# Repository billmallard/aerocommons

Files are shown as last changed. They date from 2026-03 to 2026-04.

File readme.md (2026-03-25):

# AeroCommons — MAOS Platform

### 🌐 [aerocommons.org](https://aerocommons.org) — Project website with full documentation, articles, and design updates

**Mobile Aviation Operating System**
*An open-source experimental aircraft development project*

---

> **This is a design and development project, not a flying aircraft.**
> The MAOS does not yet exist as a physical airplane. What exists right now is a growing body of engineering design work, analysis, and documentation — all of it published here as it is produced. If you found this page, you are watching the project from the beginning.

---

## What Is This?

AeroCommons is building an experimental aircraft called the **MAOS — Mobile Aviation Operating System**.

The concept: a four-seat, IFR-equipped, series-hybrid experimental aircraft that a single builder can construct in a two-car garage, transport on a road-legal trailer, and deploy from a remote airstrip without hangar support. It targets a 20,000 ft ceiling, carries TKS ice protection, and uses a novel propulsion architecture — two motorcycle-derived generator engines driving contra-rotating electric motors — that provides meaningful redundancy at every stage of the power chain.

It is designed and built under **FAA Experimental Amateur-Built (E-AB)** rules, the same regulatory framework used by thousands of homebuilt aircraft flying today. This means the builder constructs more than 51% of the aircraft themselves, and the FAA issues a special airworthiness certificate on that basis.

The MAOS does not exist yet as metal and composite. The design work is underway. This repository is where that work lives.

---

## What Is GitHub? (A Note for Pilots)

If you arrived here from the EAA forums, a fly-in conversation, or a link someone sent you, and you have never used GitHub before — welcome. Here is what you need to know.

**GitHub is a platform for storing, versioning, and collaborating on files.** It was built by software developers, so the interface can feel foreign if your world is airplanes rather than code. But the underlying idea is simple and useful for a project like this:

- Every document, drawing, and design file we produce is stored here
- Every change to every file is recorded, with a timestamp and a description of what changed and why
- Anyone in the world can read the files, download them, and propose changes
- Discussions happen in the open, attached to specific documents or topics

Think of it as a combination of a **shared filing cabinet**, a **change log**, and a **community forum** — one where the entire history of every decision is preserved and searchable.

You do not need to understand software development to participate here. You need to be willing to read, ask questions, and share your experience.

---

## Where We Are Right Now

The following formal design documents have been completed and are in the repository:

| Document | Title | Status |
|---|---|---|
| DWG MAOS-GA-001 | General Arrangement — Artist's Concept | Complete |
| DWG MAOS-PM-002 | Project Briefing — Team & Propulsion Architecture | Complete |
| MAOS-TRL-DEV-001 Rev A | Trailer & Ground Support Development Plan | Complete |
| MAOS-ECS-DEV-001 Rev B | Environmental Control System Development Plan | Complete |

**Open design decisions** currently under active analysis include: final wingspan (which drives trailer length and wing loading), flap vs. flapless configuration, HV bus voltage, propulsion motor final selection, and pressurization system design.

The design is not frozen. This is the point in the project where decisions are still being made and where experienced input has the most value.

---

## The Aircraft — Key Concepts

**Airframe:** Pod-and-boom configuration. A cylindrical pressure pod carries the crew and systems. A tail boom carries the empennage and propulsion motors. High wing with V-struts. Fixed faired tricycle gear.

**Propulsion:** Series hybrid. Two Honda 400cc motorcycle-derived engines mounted in the wing run as pure electrical generators. Their output feeds a common high-voltage bus alongside a flight battery pack. Contra-rotating electric motors on the tail boom provide thrust. No single failure produces a total power loss.

**Wing:** Single-piece removable high wing. Generators are integrated into the wing structure. Wing removal and installation uses the trailer's built-in crane system — no hangar, no forklift, no external ground equipment.

**Trailer:** A purpose-built ground support system based on an enclosed aluminum gooseneck car hauler. An overhead crane beam runs the length of the trailer interior. The aircraft is transported, deployed, and recovered entirely from the trailer. Road legal within Texas highway envelope.

**ECS:** Full climate control from first flight (v1.0), with all structural provisions for pressurization built in so that pressurization (v1.1) is an installation upgrade rather than a redesign.

**Avionics:** IFR equipped. EFIS-based glass panel. All-weather capable including TKS fluid ice protection.

**Regulatory:** FAA Experimental Amateur-Built, 51% rule. The aircraft will carry an experimental airworthiness certificate.

---

## How This Project Is Being Designed

The MAOS uses a structured **AI-assisted design methodology** that we believe is genuinely novel for homebuilt aircraft development.

Rather than using AI as a search tool or writing assistant, the project runs a **multi-agent design board** — a set of specialized AI agents assigned to Aerodynamics, Structures, Propulsion, Systems, Manufacturing, and Safety, coordinated by a Chairman agent. These agents hold formal board sessions, surface conflicts between disciplines, and produce structured decision records.

Every open design question is tracked as an explicit **decision gate**. No decision is resolved informally. Every gate has a current recommendation, a rationale, and remains open for revision until it is formally closed.

All session transcripts, agent SKILL files, board agendas, decision records, and analysis outputs are published in this repository as they are produced. The methodology itself is open — any builder can fork it and apply it to their own project.

This is not a replacement for engineering judgment. The agents surface conflicts and structure analysis. The human makes decisions.

---

## Manufacturing Philosophy

The MAOS is designed to be built by **one person with basic tools**. Not a well-equipped professional shop. A two-car garage with hand tools, a drill press, and internet access.

Primary structure uses:
- **Aluminum sheet and extrusions** — cut to DXF files by SendCutSend, OSH Cut, or equivalent. Parts arrive flat and ready to assemble.
- **Foam-core fiberglass composite** — hot-wire cut foam cores, hand-laid fiberglass. No autoclave. No CNC.
- **3D printed tooling and formers** — FDM for jigs, fixtures, and non-structural components. Never primary structure.
- **COTS hardware** — McMaster-Carr, Aircraft Spruce, standard commercial sources for everything else.

All design files are published in open formats: STEP, STL, DXF. Primary CAD tools are FreeCAD and OpenVSP. No vendor lock-in.

---

## How to Follow This Project

**You do not need an account to read everything in this repository.** All documents, drawings, and files are publicly visible.

If you want to do more than read:

### ⭐ Star the repository
The star button is in the top-right corner of this page. Starring a repository on GitHub is the equivalent of bookmarking it and telling the platform you find it interesting. It helps the project be discovered by others, and it tells us the work is reaching people.

### 👁️ Watch the repository
The **Watch** button (also top-right) lets you subscribe to activity. You can choose to be notified when new documents are published, when discussions open, or when decisions are recorded. You can tune the notification level to whatever suits you — from everything to only major releases.

### 💬 Join the Discussions
The **Discussions** tab at the top of this page is where the community conversation happens. You can:
- Ask questions about the design
- Share experience from your own builds or flying that's relevant to a design decision
- Follow threads on specific topics (propulsion, trailer ops, avionics, etc.)
- Propose an idea or flag a concern

Discussions are indexed and searchable. A question you ask today may help a builder three years from now.

### 🐛 Open an Issue
If you spot a problem in a document — a calculation that doesn't look right, a specification that conflicts with another, or a decision that seems to be missing — open an **Issue**. The Issues tab is designed for exactly this. It creates a tracked record of the concern and ensures it gets addressed.

### 🍴 Fork the Repository
If you want your own copy of the design files to experiment with, propose major changes, or adapt for your own project, you can **Fork** the repository. This creates a complete copy under your own GitHub account. Any changes you make to your fork are yours — and if you want to propose those changes be incorporated into the main project, you submit a **Pull Request**.

---

## Who We Are Looking For

The MAOS is a serious engineering project aimed at building a real aircraft. The people who will make it successful are:

- **Experienced homebuilders** who have completed or are building EAA projects and can ground-check design assumptions against shop reality
- **Pilots** — particularly those with IFR, mountain, or backcountry experience who can speak to the operational requirements the design is meant to serve
- **Aerospace and mechanical engineers** who want to apply professional judgment to a project that actually matters to them
- **Makers and fabricators** with composite, aluminum, or electrical skills
- **Software and firmware developers** interested in the open-source FADEC and control systems

You do not have to be credentialed to contribute. You have to be serious, specific, and willing to be wrong.

---

## Principles

1. **Safety through design, not pilot skill.** The aircraft must be inherently stable and departure-resistant. A bad moment should not become a fatal one.
2. **If a determined amateur cannot build it, the design has failed.** Complexity is a bug, not a feature.
3. **Weight is always the enemy.** Every component justifies its existence in grams, not just function.
4. **Open from the first session.** Nothing is held back for a later announcement. The work is public as it happens.
5. **The 51% rule is the design rule.** The builder-fabricated portions are the capable, interesting, achievable portions — not a compliance exercise.

---

## Links

- **Website:** [aerocommons.org](https://aerocommons.org)
- **Contact:** [contact@aerocommons.org](mailto:contact@aerocommons.org)
- **Discussions:** [github.com/billmallard/aerocommons/discussions](https://github.com/billmallard/aerocommons/discussions)

---

*AeroCommons is an open-source experimental aircraft development project. The MAOS has not yet flown. All specifications are design targets subject to revision. Nothing in this repository constitutes airworthiness approval or certification of any kind. Build and fly at your own judgment and risk.*

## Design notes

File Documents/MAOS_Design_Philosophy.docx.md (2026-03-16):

**MOBILE AVIATION OPERATING SYSTEM**

*Project Design Philosophy & North Star Statement*

Version 0.1  //  March 2026  //  DRAFT

# **North Star Statement**

*This aircraft is designed as a complete mobile aviation operating system. The airplane and trailer are co-equal components, designed together from first principles. The system requires no fixed infrastructure — no hangar, no FBO, no ground crew. A single pilot can deploy, operate, and recover the system from any suitable airstrip.*

*Every design decision is evaluated against this principle. Complexity that serves the operating system is acceptable. Complexity that serves only aesthetics or marginal performance gains is rejected. The airplane must be buildable, maintainable, and operable by one person with the tools that travel with it.*

This is the filter through which every design decision passes. When tempted to add a feature, add weight, or add complexity, return here first.

# **What This Is — And Is Not**

This is not a trailerable airplane. Trailerable airplanes tolerate being trailered. This system is designed around the trailer as a first-class component from day one.

The distinction matters because it changes every priority:

* A trailerable airplane compromises to fit on a trailer. This airplane is designed with the trailer as its ground station.

* A trailerable airplane stores in a hangar and occasionally gets trailered. This system has no hangar — the trailer is the hangar.

* A trailerable airplane requires two people and a forklift to rig. This system deploys solo, in under an hour, from a pickup truck.

The closest analogy is a boat on a trailer. The owner arrives at any suitable body of water, launches, operates, recovers, and drives away. No marina slip required. No dock fees. No dependence on fixed infrastructure. This is that — for aviation.

# **What This System Enables**

The operating system concept transforms the owner's cost structure and operational freedom completely:

* No hangar lease — potentially the single largest recurring cost in personal aviation, eliminated.

* No dependence on FBO services for routine operations.

* Maintenance at home, in the trailer, with the integrated workbench and tool storage.

* The airplane can be stored at home, in a driveway, legally — like a boat.

* Fly from any suitable strip in a region, not just home base. Tow to a new area and operate from there.

* True cross-country independence: depart from a grass strip, land at a paved field, drive the trailer to meet yourself if needed.

The lifestyle this enables is different in kind, not just degree. This is not flying from Airport A to Airport B and back. This is towing your operating system to a region, flying from multiple local strips, and moving on when ready.

# **Design Philosophy**

## **Rutan's Rule**

Safety through inherent stability. The configuration must resist departure without demanding pilot heroics. A bad moment must not become a fatal moment.

## **Bede's Rule**

If a determined amateur with modest tools cannot build this, the design has failed before it flew. Complexity is a bug, not a feature. A sophisticated airplane can and should be buildable by one person in a two-car garage on a reasonable budget.

## **The Operating System Rule**

Every component — airframe, powerplant, systems, trailer, crane — is evaluated as part of a single integrated system. A component that is excellent in isolation but degrades the operating system is the wrong component.

When a design decision is genuinely uncertain, ask: which choice better serves the solo operator at a remote strip with the tools in the trailer?

# **Design Priorities**

In strict order. A lower priority never overrides a higher one.

1. Stall/departure resistance — canard or inherently safe configuration preferred.

2. Structural simplicity — minimum part count, minimum joints, minimum skill at each build step.

3. Repairability in the field with basic tools and materials from Aircraft Spruce or equivalent.

4. Performance — efficiency and speed matter, but not at the cost of priorities 1–3.

5. Aesthetics — a good design looks right, but ugly flies fine.

# **The Decision Filter**

Before accepting any design feature, ask these questions in order:

* Does this serve the operating system, or only the airplane?

* Can a competent amateur build or repair this with tools that travel in the trailer?

* What does this weigh, and does it justify that weight?

* If this fails at a remote strip, what is the recovery path?

* Does "that's how production aircraft do it" justify this — or is that a lazy answer?

If a feature cannot survive this filter, it does not belong in the design. Note the idea in the design log and move on.

# **Non-Negotiable Constraints**

These are not preferences. They are constraints that define what this project is.

* Never propose a feature that requires a professional machine shop to fabricate.

* Never accept retractable gear on the primary design — the complexity and failure modes are incompatible with the operating system concept.

* Never optimize for aesthetics at the expense of buildability.

* Never ignore weight — always ask what the lightest acceptable solution is before proposing a heavier one.

* Never design around a single-source supplier with no track record in the homebuilder community.

# **Current Configuration Snapshot**

This is the working design as of initial concept phase. All figures are targets subject to revision.

## **Airframe**

**Configuration:**  High-wing, pod-and-boom, tricycle gear, fixed faired main gear

**Seats:**  4 (wide cabin — 46" minimum, Cherokee Six reference)

**Wing:**  One-piece, removable, tubular aluminum spar (BD-4 inspired), laser-cut ribs

**Wing area:**  \~140 ft²  |  Span: \~37.4 ft  |  AR: 10  |  Loading: \~17.5 lbs/ft²

**Airfoil:**  Riblett GA35-615 (15% root / 12% tip) — working assumption

**Primary structure:**  Aluminum semi-monocoque; flat-cut parts from SendCutSend

**IFR / Ice:**  IFR capable; TKS ice protection preferred

## **Powerplant (Primary Path)**

**Engine:**  Viking 195T (Honda-based, 195 HP, turbocharged, FADEC, mogas)

**Alternates:**  ULPower UL520T; Kawasaki Inline 4 Turbo (provision only, pending certification)

**Cooling:**  Liquid-cooled; heat exchanger provides cabin heat

## **Performance Targets**

**Cruise:**  155 KTAS

**Range:**  1,000 nm  |  Endurance: 7 hrs (5 hrs flying \+ reserves)

**Useful load:**  1,200 lbs including fuel

**Gross weight:**  \~2,430 lbs

**Empty weight target:**  \~1,230 lbs

**Service ceiling:**  17,500–20,000 ft

## **Trailer System**

**Concept:**  Integrated ground station — horizontal boom crane deploys from trailer roof

**Crane:**  Horizontal boom, min. half-wingspan reach; rotating cradle engages wing at strut fittings

**Sequence:**  Disconnect 4 pins \+ QD fittings, lift 6", rotate 90°, retract — wing stowed

**Target time:**  \~65 min solo (45 min with practice)

**Trailer features:**  Shore power, inverter, workbench, tool storage, wing stowed above fuselage

**Regulatory:**  FAA Experimental Amateur-Built (51% rule)

*This document is the project north star. Return to it before accepting any design change that adds weight, complexity, or dependency on fixed infrastructure. If a decision is consistent with this document, it is probably right. If it conflicts, it requires extraordinary justification.*

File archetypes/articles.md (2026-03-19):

---
title: "{{ replace .Name "-" " " | title }}"
date: {{ .Date }}
description: ""
tags: []
author: "AeroCommons Design Board"
session: ""
summary: ""
draft: false
---

<!-- 
  AEROCOMMONS ARTICLE TEMPLATE
  ─────────────────────────────
  title:       Full title of the post
  date:        ISO 8601 — YYYY-MM-DDTHH:MM:SS-06:00
  description: One sentence shown in article cards and meta tags
  tags:        Array of lowercase tags e.g. ["board-meeting", "propulsion", "structures"]
  author:      Who or what produced this (e.g. "AeroCommons Design Board")
  session:     Optional — board session ID if applicable (e.g. "BOARD-004")
  summary:     Optional — override for the article card excerpt
  draft:       Set to true to publish to repo without displaying on site
-->

Body content begins here. Markdown is fully supported.

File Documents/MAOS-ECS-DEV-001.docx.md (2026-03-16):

  
**MAOS AIRCRAFT PROJECT**

**Environmental Control System**

Development Plan

Pressurization · Climate Control · Controller Electronics

Document: MAOS-ECS-DEV-001  
Revision: A (Draft)  
Date: March 12, 2026

# **1\. System Overview & Design Philosophy**

The MAOS Environmental Control System (ECS) provides cabin pressurization, heating, cooling, ventilation, and dehumidification as a single integrated subsystem. Unlike conventional light aircraft that bleed compressed air from engine turbochargers, the MAOS ECS is fully electric: all compressors, fans, valves, and controllers run from the aircraft DC electrical bus with no pneumatic connections to the wing-mounted generators.

This architecture is driven by the pod-and-boom configuration. The wing-to-pod interface is the primary modularity boundary for transport and assembly. Keeping the ECS entirely within the pod means that wing attachment and removal requires only structural fasteners, electrical connectors, and fuel quick-disconnects. No hot pneumatic ducting crosses this boundary.

## **1.1 Design Requirements**

| Parameter | Requirement |
| :---- | :---- |
| Cabin volume | \~150–180 cu ft (4 occupants \+ baggage) |
| Max flight altitude | 25,000 ft (Kawasaki engine max operating) |
| Target cabin altitude | 8,000 ft maximum at all flight altitudes |
| Max differential pressure | 5.5 psi (at 25,000 ft / 8,000 ft cabin) |
| Normal differential | 3.5 psi (at 20,000 ft / 8,000 ft cabin) |
| Ventilation flow | 10 CFM/person minimum, 40–60 CFM total |
| Ground cooling | Full AC at 40°C ambient, 4 occupants, sun load |
| Ground heating | Cabin to 20°C from \-10°C ambient within 10 min |
| Max ECS power draw | 5 kW peak (ground hot day), 2–3 kW cruise |
| Target weight (complete) | 18–25 kg (40–55 lbs) all-in |
| Pod-external connections | Electrical only. Zero pneumatic connections. |

## **1.2 System Architecture Summary**

The ECS consists of two independent compression loops plus shared distribution and controls:

* **Pressurization loop:** Electric air compressor draws ambient air through filtered pod inlet, compresses to cabin pressure, delivers to mixing plenum. Outflow valve on aft bulkhead regulates cabin pressure.

* **Climate loop:** Closed-circuit vapor-cycle refrigerant system (R-1234yf) with reversible heat pump capability. EV-class scroll compressor, condenser with ram air and electric fan, evaporator in cabin air path, electronic expansion valve.

* **Controls:** Custom ESP32-based controller managing both loops, cabin pressure regulation, temperature control, safety interlocks, and CAN bus integration with aircraft systems.

# **2\. Development Phases**

Development proceeds in five phases. The key principle is that each phase produces a testable system that validates assumptions before committing to the next level of integration. The pod-only architecture makes this possible: every phase through Phase 3 can be tested on the ground with the pod on its trailer.

| Phase | Objective | Deliverable | Duration | Cost Est. |
| :---- | :---- | :---- | :---- | :---- |
| 1 | Requirements & component selection | BOM, schematic, sourced parts | 6–8 weeks | $2,000–$3,500 |
| 2 | Bench test rig | Working ECS on open frame | 8–12 weeks | $3,000–$5,000 |
| 3 | Pod integration | ECS installed in pressure shell | 8–12 weeks | $2,000–$4,000 |
| 4 | Ground pressure test | Sealed pod holds 5.5 psi diff. | 4–6 weeks | $500–$1,500 |
| 5 | Flight test integration | ECS operational in flight | Ongoing | Incl. in flight test |

## **2.1 Phase 1: Requirements Lockdown & Component Selection**

**Duration:** 6–8 weeks

**Objective:** Finalize thermal loads, select all major components, produce complete bill of materials, and design the controller electronics for PCB outsourcing.

### **2.1.1 Thermal Load Analysis**

Before selecting hardware, quantify the actual thermal loads for the three design cases:

1. **Ground hot day (design driver):** 40°C ambient, direct solar through windscreen (\~800 W/m² on \~0.5 m² glazing \= 400W solar gain), 4 occupants at 100W metabolic each, avionics heat \~100W. Total cooling load approximately 900–1,100W. Add safety margin: size climate compressor for 3–4 kW cooling capacity.

2. **Cruise at 20,000 ft:** OAT approximately \-25°C, pressurization compressor adds \~40°C to inlet air, cabin heat loss through fuselage skin significant. Net heating load likely 500–800W. Heat pump mode or pressurization compression heat may suffice.

3. **Cold soak / ground cold:** \-10°C ambient, need to warm cabin to 20°C. Heat pump COP drops at low ambient temps. May need supplemental resistive heat element (\~1 kW PTC heater as backup) for initial warmup.

### **2.1.2 Component Selection**

All major components should be selected during this phase. The following table identifies the target components and selection criteria:

| Component | Target Specification | Sourcing Notes |
| :---- | :---- | :---- |
| Pressurization compressor | Electric centrifugal or scroll, 60 CFM at 2:1 PR, 12–48V or 200–400V DC, \<4 kg | EV/fuel cell air supply units (e.g., Busch, Rotrex, Thomas). Evaluate automotive fuel cell cathode air compressors. |
| Climate compressor | EV scroll compressor, R-1234yf, 3–4 kW cooling, 200–400V DC, \<7 kg | Denso, MAHLE, Hanon Systems, Valeo. Used EV parts from Tesla Model 3/Y, Hyundai Ioniq salvage as test units. |
| Condenser | Microchannel, \~2–3 kW rejection, ram air \+ 12V fan, \<3 kg | Automotive universal condensers. Size for ground ops with fan only (no ram air). |
| Evaporator | Compact plate-fin, fits under-floor or behind panel, \<2 kg | Universal automotive evaporator cores. Custom bracket via 3D print / sheet aluminum. |
| Outflow valve | Motorized butterfly or poppet, 2–3 in diameter, proportional control | COTS motorized damper or custom: stepper motor \+ 3D-printed or waterjet butterfly. Fail-open design mandatory. |
| Expansion valve | Electronic expansion valve (EEV), R-1234yf rated | Danfoss, Sanhua, or automotive OEM. EEV preferred over TXV for heat pump reversibility. |
| Reversing valve | 4-way valve for heat pump mode | Standard HVAC 4-way reversing valve, R-1234yf compatible. |
| Cabin pressure sensor | Absolute pressure, 0.1% accuracy, 6–15 psia range | Honeywell ABP2 series or TE MS5611. Dual redundant. |
| Temperature sensors | NTC thermistors or digital (DS18B20), cabin \+ evap \+ condenser \+ ambient | Commodity parts. 6–8 sensors total across system. |
| Dump valve | Manual cable-actuated, 3–4 in, fail-open | Aircraft Spruce or custom. Pilot-accessible red handle, zero electrical dependency. |
| PTC heater (backup) | 1–2 kW, 12V or HV DC, self-regulating | Automotive PTC cabin heater elements. Compact, intrinsically safe. |

### **2.1.3 Controller Electronics Design**

The ECS controller is the heart of the system and the primary custom-development effort. It manages cabin pressure regulation, climate control, safety interlocks, and system health monitoring. The architecture uses an ESP32-S3 as the main processor with purpose-built I/O and power driver boards.

**Controller architecture:** One main controller board (ESP32-S3) handles all ECS logic. A separate power driver board carries the high-current switching for compressor enable, fan PWM, valve actuation, and PTC heater switching. The two boards connect via a ribbon cable. This separation keeps noise-sensitive analog sensing away from high-current switching.

Phase 1 deliverables for electronics:

1. Complete schematic capture in KiCad (open-source, PCB fab houses accept natively)

2. Bill of materials with LCSC/DigiKey/Mouser part numbers for all components

3. PCB layout to 90% completion, ready for review before sending to fab

4. Firmware architecture document defining state machines, control loops, and CAN message definitions

5. Gerber files and pick-and-place files ready for JLCPCB or PCBWay assembly

### **2.1.4 Main Controller Board — Block Diagram**

The main board includes:

* **ESP32-S3-WROOM-1 module:** Dual-core 240 MHz, WiFi/BLE for ground diagnostics and firmware updates, sufficient ADC channels and GPIO.

* **Pressure sensing:** Dual redundant absolute pressure sensors (SPI or I2C), 0.1% accuracy. Cross-checked in firmware; disagreement triggers alert.

* **Temperature inputs:** 8-channel analog mux for NTC thermistors (cabin air, evaporator surface, condenser air, ambient inlet, compressor discharge, refrigerant suction, refrigerant discharge, electronics enclosure).

* **Humidity sensor:** SHT40 or BME280 for cabin humidity monitoring and dehumidification control.

* **CAN transceiver:** SN65HVD230 or MCP2562 for integration with aircraft CAN bus. Receives altitude, airspeed, and electrical bus status. Transmits ECS status and alerts.

* **Display interface:** SPI output to a small TFT or OLED for maintenance/debug. In flight, ECS status displays on the primary EFIS via CAN.

* **SD card slot:** Flight data logging of all ECS parameters at 1 Hz for post-flight analysis.

### **2.1.5 Power Driver Board — Block Diagram**

The power driver board includes:

* **Pressurization compressor driver:** If using a brushless DC compressor, either an integrated inverter (preferred) or an external ESC. Enable/speed command from main controller via PWM or analog voltage.

* **Climate compressor driver:** EV scroll compressors typically include an integrated inverter accepting a CAN or PWM speed command. The power board provides the HV DC contactor and precharge circuit.

* **Fan PWM outputs:** 2 channels (condenser fan, cabin recirculation fan), MOSFET-driven, 12V, 5A each.

* **Outflow valve driver:** Stepper motor driver (TMC2209 or A4988) for proportional valve control. Endstop inputs for full-open and full-closed positions.

* **EEV driver:** Stepper driver for electronic expansion valve (500-step typical).

* **Reversing valve:** Relay or MOSFET for 4-way valve solenoid actuation.

* **PTC heater switching:** High-side MOSFET switch with current sensing for the backup heater element.

* **Power monitoring:** INA226 or equivalent for bus voltage and current measurement on both LV (12/28V) and HV (if applicable) buses.

## **2.2 Phase 2: Bench Test Rig**

**Duration:** 8–12 weeks

**Objective:** Prove the thermodynamics, validate component selections, tune the control loops, and identify integration issues before touching the actual pod.

The bench rig is the most important phase. It catches problems when they are cheap to fix. Build it on a workbench or rolling cart using a simplified test enclosure.

### **2.2.1 Test Enclosure**

Build a sealed plywood or insulated foam box roughly approximating the pod internal volume (about 4 ft × 4 ft × 8 ft). It does not need to hold 5.5 psi differential. Use a shop vacuum or auxiliary blower connected to the outflow path to simulate cabin leakage and draw air through the system. The goal is airflow and thermal testing, not pressure testing.

For the pressurization compressor specifically, test it against a throttled outlet to confirm it can achieve the required pressure ratio and flow rate at the expected inlet pressures. You cannot simulate 20,000 ft ambient pressure on a bench, but you can verify the compressor performance curve and extrapolate.

### **2.2.2 Bench Test Sequence**

1. **Climate loop only (no pressurization):** Charge refrigerant circuit, run cooling mode, verify evaporator temperature, condenser rejection, and cabin temperature pulldown in the test box. Tune EEV superheat control.

2. **Heat pump mode:** Reverse the 4-way valve, verify heating capacity and COP at various ambient conditions. Test defrost logic if evaporator ices.

3. **Pressurization compressor:** Run independently. Measure flow vs. pressure ratio curve. Verify discharge temperature. Test speed control response.

4. **Combined operation:** Run both loops simultaneously. Verify no interactions (electrical noise, vibration coupling). Test worst-case power draw.

5. **Controller integration:** Install the prototype PCBs. Run automated test sequences. Verify all sensor readings, actuator responses, safety interlocks. Test CAN bus communication with a simulated aircraft bus.

6. **Failure mode testing:** Simulate sensor failures (disconnect each sensor individually), compressor failures (kill power to each compressor), and electrical bus faults. Verify the controller responds correctly to each scenario.

### **2.2.3 Instrumentation**

The bench rig should be heavily instrumented beyond what the flight controller needs. Add a USB data acquisition system logging at 10 Hz minimum, with thermocouples at every point in the refrigerant circuit, pitot tubes in the air ducts for flow measurement, a watt meter on the electrical supply, and a refrigerant pressure gauge set. This data validates the thermal model and catches issues the flight sensors might miss.

## **2.3 Phase 3: Pod Integration**

**Duration:** 8–12 weeks

**Objective:** Install the proven bench system into the actual pod structure, route ducting, mount the condenser, seal penetrations, and verify fitment.

By this point, the thermodynamics are validated and the controller is tuned. This phase is about packaging, routing, and sealing. The pod is on the trailer with no wing attached. Shore power (120/240V AC via an inverter or directly) drives the system.

Key integration tasks:

1. **Condenser mounting:** Install on lower aft pod surface with NACA scoop or flush inlet for ram air. Verify fan-only ground cooling capacity before assuming any ram air credit.

2. **Evaporator installation:** Mount in under-floor plenum or behind aft cabin panel. Route cabin air recirculation ducting. Verify condensate drain path exits the pressure shell through a trapped drain (P-trap or check valve to prevent pressure loss).

3. **Pressurization inlet:** Install filtered inlet on pod exterior with rain/FOD protection. Route to pressurization compressor. Consider inlet location relative to exhaust and engine fumes.

4. **Outflow valve:** Install on aft pressure bulkhead. Verify full-open and full-closed positions. Test manual dump valve independently.

5. **Controller and wiring:** Mount controller enclosure in avionics bay area. Route sensor wiring and power cables. Verify EMI compatibility with avionics. Test CAN bus through actual aircraft harness.

6. **Seal all penetrations:** Every wire, tube, and control cable passing through the pressure shell gets a sealed bulkhead fitting. Document every penetration location and sealing method.

## **2.4 Phase 4: Ground Pressure Test**

**Duration:** 4–6 weeks

**Objective:** Prove the pod holds the design differential pressure with acceptable leak rate. This is the structural validation of the pressure vessel.

This is the first time you pressurize the actual pod to 5.5 psi differential. This is a significant structural test and must be conducted carefully:

1. **Pre-test inspection:** Visual inspection of all seams, bulkheads, penetrations, and the windscreen seal. Fix anything that looks questionable before pressurizing.

2. **Incremental pressurization:** Increase in 0.5 psi steps with 5-minute holds at each step. Listen for creaking, popping, or air leaks at every step. Abort and investigate any anomaly.

3. **Proof pressure:** Hold at 1.33× design differential (7.3 psi) for a minimum duration per your structural analysis requirements. This is a one-time proof test, not a cyclic fatigue test.

4. **Leak rate measurement:** At design pressure (5.5 psi), shut off the pressurization compressor and measure cabin pressure decay rate over 30 minutes. Calculate leak rate in CFM. Target: the pressurization compressor can maintain pressure with margin to spare.

5. **ECS functional test under pressure:** Run the complete ECS while the pod is pressurized. Verify outflow valve regulation, temperature control, and all controller functions under actual pressure differential.

**Safety note:** A 52-inch-diameter cylinder at 5.5 psi contains significant stored energy. Conduct pressure testing outdoors or in a well-ventilated space. Keep all personnel clear of the windscreen and any large flat panels during pressurization. A catastrophic failure at 5.5 psi is survivable at distance but can cause serious injury if you are leaning against a panel that lets go.

## **2.5 Phase 5: Flight Test Integration**

**Duration:** Ongoing (part of the overall MAOS flight test program)

**Objective:** Validate ECS performance at actual cruise altitudes and across the full flight envelope.

ECS flight testing is integrated into the broader MAOS flight test program. The system should be installed but operated unpressurized during initial flight tests, with the outflow valve locked open. This allows the controller to log altitude, ambient conditions, and system responses without imposing pressure loads on a structure that is being validated for other things simultaneously.

Pressurized flight testing begins only after the aircraft has demonstrated satisfactory handling qualities and structural integrity through the initial flight test envelope expansion. ECS-specific flight test points include cabin pressure control during climb and descent, temperature regulation across the altitude envelope, emergency depressurization from maximum differential, and single-generator-failure operation.

# **3\. Controller Firmware Architecture**

The ECS firmware runs on the ESP32-S3 using FreeRTOS. The architecture uses three main tasks running at different rates, plus interrupt-driven CAN communication.

## **3.1 Task Structure**

| Task | Rate | Responsibility |
| :---- | :---- | :---- |
| Pressure Control | 10 Hz | Read pressure sensors, compute cabin altitude and rate of change, command outflow valve position and pressurization compressor speed via PID loop. Safety checks for overpressure and excessive rate of change. |
| Climate Control | 1 Hz | Read temperature and humidity sensors, compute heating/cooling demand, command climate compressor speed, fan speeds, EEV position, and reversing valve state. Superheat monitoring and protection. |
| System Health | 0.5 Hz | Cross-check redundant sensors, monitor bus voltage and current, check compressor operating parameters against limits, manage SD card logging, handle WiFi diagnostics connection, transmit CAN status messages. |

## **3.2 State Machine**

The ECS operates in five primary states:

* **OFF:** System powered but all actuators inactive. Entered on power-up and on pilot command.

* **GROUND (unpressurized):** Climate control active, pressurization compressor off, outflow valve locked open. Used for ground operations, taxi, and initial climb below transition altitude.

* **PRESSURIZING:** Transitional state during climb. Outflow valve modulating closed, pressurization compressor ramping up. Cabin rate of change limited to 500 ft/min equivalent for passenger comfort.

* **CRUISE (pressurized):** Both loops active, cabin pressure regulated to schedule. This is the normal in-flight state above transition altitude.

* **DEPRESSURIZING:** Transitional state during descent. Outflow valve opening, pressurization compressor ramping down. Cabin rate of change limited to 300 ft/min equivalent.

Emergency states (entered automatically or by pilot action):

* **DUMP:** Pilot pulls manual dump handle. Outflow valve driven full open. Pressurization compressor off. Climate continues if power available. Non-recoverable without pilot reset.

* **FAULT:** Controller detects sensor disagreement, overpressure, or actuator failure. Outflow valve driven to safe position (open or cracked, depending on failure mode). Alert on CAN bus and annunciator.

## **3.3 Cabin Pressure Schedule**

The controller maintains cabin altitude according to a schedule based on actual aircraft altitude (received via CAN bus from the air data computer or GPS altitude). A simple linear schedule works well:

* Sea level to 8,000 ft aircraft altitude: cabin unpressurized (1:1 with ambient)

* 8,000 to 25,000 ft aircraft altitude: cabin altitude held at 8,000 ft (differential increases from 0 to \~5.5 psi)

* Rate limiting: cabin altitude change rate capped at 500 ft/min climb, 300 ft/min descent regardless of aircraft rate

The pilot can override the schedule to request a lower cabin altitude (higher differential) or manual control of the outflow valve for abnormal situations. Override requires a deliberate two-step input to prevent accidental engagement.

# **4\. Safety & Failure Modes**

Every failure mode must result in a safe condition without pilot intervention. The fundamental principle: loss of pressurization is uncomfortable but not immediately dangerous. The aircraft can always descend. Loss of structural integrity of the pressure vessel is the only catastrophic failure mode, and that is addressed by structural design and proof testing, not by the ECS controller.

## **4.1 Failure Mode Summary**

| Failure | Automatic Response | Pilot Action Required |
| :---- | :---- | :---- |
| Pressurization compressor failure | Outflow valve holds position, cabin slowly depressurizes as leakage exceeds zero inflow | Descend to unpressurized altitude or don supplemental O2 |
| Climate compressor failure | Climate loop shuts down, pressurization continues normally | Accept temperature discomfort. Open vents for ventilation. |
| Outflow valve stuck closed | Pressurization compressor speed reduced. Safety relief valve opens at max differential \+ 0.5 psi | Monitor cabin pressure. Use manual dump if needed. |
| Outflow valve stuck open | Pressurization compressor at max speed. If unable to maintain cabin altitude, alert pilot. | Descend to unpressurized altitude. |
| Pressure sensor disagreement | Use remaining good sensor. If both suspect, drive outflow valve to mid-position and alert pilot. | Manual pressure control or descend. |
| Total electrical failure | Outflow valve spring-returns to full open (fail-safe). Both compressors stop. | Aircraft is now unpressurized. Descend. Manual dump available (cable, no electrical). |
| Windscreen seal failure | Rapid cabin pressure loss. Controller detects rate and shuts down pressurization compressor. | Don O2, descend immediately. Structural: windscreen retained by mechanical stops. |
| Refrigerant leak | Climate compressor shuts down on low suction pressure. Alert pilot. | No immediate safety concern. Climate comfort only. |

## **4.2 Mandatory Safety Hardware (Non-Electronic)**

These items operate with zero electrical power and zero controller involvement:

* **Manual dump valve:** Cable-actuated, red T-handle accessible to pilot. Mechanically opens a 3–4 inch port in the pressure shell. No electronics in the path.

* **Positive pressure relief valve:** Spring-loaded, set to open at max differential \+ 0.5 psi (6.0 psi). Prevents overpressure even if the controller and outflow valve both fail simultaneously.

* **Negative pressure relief valve:** Prevents external pressure from exceeding cabin pressure during rapid descent. Spring-loaded inward-opening flap.

* **Outflow valve return spring:** If the stepper motor loses power or the controller fails, the outflow valve spring-returns to full open. Fail-safe to unpressurized.

# **5\. Weight & Power Budget**

## **5.1 Weight Breakdown**

| Component | Weight (kg) | Notes |
| :---- | :---- | :---- |
| Pressurization compressor \+ motor | 3.0–4.0 | Centrifugal preferred for weight |
| Climate scroll compressor \+ inverter | 5.0–7.0 | EV HVAC unit, integrated inverter |
| Condenser \+ fan | 2.0–3.0 | Microchannel automotive |
| Evaporator | 1.0–2.0 | Compact plate-fin |
| Refrigerant lines, EEV, receiver-drier, reversing valve | 2.0–3.0 | Standard automotive |
| Outflow valve \+ actuator | 0.5–1.0 | Custom: waterjet butterfly \+ stepper |
| Relief valves (positive \+ negative) | 0.5–1.0 | Aircraft-grade spring valves |
| Manual dump valve \+ cable | 0.3–0.5 | Cable-actuated, mechanical |
| PTC backup heater | 0.5–1.0 | Automotive PTC element |
| Controller boards \+ wiring harness | 1.0–1.5 | ESP32 \+ power driver \+ harness |
| Ducting, plenum, brackets, inlet filter | 2.0–3.0 | 3D-printed formers \+ fabric duct or sheet aluminum |
| TOTAL | 17.8–27.0 | Target: \<25 kg (55 lbs) |

## **5.2 Electrical Power Budget**

| Consumer | Power (kW) | Condition |
| :---- | :---- | :---- |
| Pressurization compressor | 1.5–2.0 | Cruise at 20,000–25,000 ft |
| Climate compressor (cooling) | 2.0–3.0 | Ground hot day (peak) |
| Climate compressor (cruise) | 0.5–1.5 | Cruise (reduced load) |
| Condenser fan | 0.1–0.2 | Ground ops (max); ram air reduces in flight |
| Cabin recirc fan | 0.05–0.1 | Continuous |
| PTC heater (if used) | 1.0–2.0 | Cold ground startup only |
| Controller \+ sensors \+ valves | 0.02–0.05 | Continuous |
| TOTAL — worst case ground | 4.0–5.5 | Hot day, full cooling, no pressurization |
| TOTAL — typical cruise | 2.0–3.5 | Pressurized, moderate climate load |

With twin wing-mounted generators producing well over 100 kW combined electrical output, the ECS represents approximately 2–5% of available bus power. This is negligible and leaves ample margin for all other electrical consumers.

# **6\. Open Questions & Decisions Needed**

The following items require resolution before or during Phase 1\. Each represents a design decision that affects multiple downstream components:

4. **Bus voltage for ECS:** The aircraft electrical architecture needs to be defined sufficiently to select compressor voltage ratings. If the main bus is high-voltage DC (e.g., 270V or 350V, common in series hybrid architectures), the EV climate compressor runs natively. If the bus is 48V or 28V, a DC-DC converter or different compressor selection is needed. The pressurization compressor may run on a different voltage than the climate compressor.

5. **Refrigerant choice:** R-1234yf is the automotive standard and has favorable environmental properties (low GWP). R-134a is cheaper and has a wider component ecosystem. Both work. R-1234yf is mildly flammable (A2L classification) which requires consideration for an enclosed pressurized cabin, though automotive use in enclosed vehicles is considered safe. Decision needed.

6. **Pod cross-section geometry:** The pressurization loads are directly affected by whether the pod is a true circle, an ellipse, or a cylinder-with-flat-segments. This must be resolved before structural analysis of the pressure shell. A true \~55-inch-diameter circle is structurally ideal.

7. **Windscreen design:** The windscreen is the weakest link in any pressurized cabin. Flat panels in pressurized fuselages require heavy frames. Curved windscreens are structurally efficient but optically complex. The windscreen geometry must be designed for pressure from the start.

8. **Transition altitude:** At what altitude does the system begin pressurizing? 8,000 ft (start of cabin altitude schedule) is the logical choice, but this could be pilot-selectable. Affects controller logic and the climb/descent profiles.

9. **Shore power interface:** For pre-cooling on the ground, the system needs a way to run from external power. Define the connector type, voltage, and power level. A standard J1772 EV charging connector is an interesting option if the aircraft HV bus is compatible.

10. **Oxygen system integration:** Supplemental oxygen is required above 12,500 ft (FAR 91.211) if the pressurization system is inoperative or not yet activated. The ECS plan should define how the O2 system interfaces, even though O2 is a separate subsystem.

**Next action:** Resolve the bus voltage question (item 1\) and pod cross-section geometry (item 3\) as they gate the most Phase 1 work. Everything else can be decided in parallel with Phase 1 execution.

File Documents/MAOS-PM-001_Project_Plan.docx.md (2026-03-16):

  
**MOBILE AVIATION**  
**OPERATING SYSTEM**

*Project Plan  ·  Team Architecture  ·  Agentic AI Integration*

| Document | MAOS-PM-001  Rev A |
| :---- | :---- |
| **Date** | March 2026 |
| **Status** | Active — Concept Phase |
| **Regulatory** | FAA Experimental Amateur-Built (51% Rule) |
| **Propulsion** | Series hybrid — ICE generator \+ dual rim-drive electric motors |
| **Config** | Pod-and-boom, high wing, fixed gear, 4-seat |
| **Performance** | 155 KTAS cruise, 17,500 ft service ceiling, 1,000 nm range |

| NORTH STAR | MAOS is a complete mobile aviation operating system. The airplane and trailer are co-equal components designed together from first principles. The system requires no fixed infrastructure. A single pilot can deploy, operate, and recover the system from any suitable airstrip. Every design decision is evaluated against this principle. |
| :---: | :---- |

# **1 — Concept Summary**

MAOS is not a controversial airplane. It is a novel assemblage of proven technologies on a new platform. Series hybrid drivetrains power locomotives and submarines. Rim-drive motors exist in marine propulsion. Contra-rotating propellers are standard in high-performance aviation. Pod-and-boom fuselages have flown for decades. The innovation is the integration: a coherent system designed from the ground up around complete operational independence from fixed infrastructure.

## **1.1  The Core Differentiators**

| Element | Conventional | MAOS Approach | Advantage |
| :---- | :---- | :---- | :---- |
| Propulsion | Single ICE, direct drive, CS prop | Series hybrid: ICE generator \+ dual rim-drive electric | No asymmetric thrust, full power at altitude, graceful failure |
| Engine failure | Emergency — seconds to respond | Generator fails → battery sustains → managed descent | Minutes to respond, not seconds |
| Infrastructure | Fixed hangar, FBO required | Trailer carries all support | Operates from any suitable airstrip |
| Power at altitude | ICE loses \~3%/1,000 ft | Electric motors unaffected by altitude | Full performance at service ceiling |
| Prop system | CS prop, governor, gearbox | Fixed-pitch or folding, direct drive | Lower cost, no governor failure mode |
| Safety | Depends on single engine | Redundant generators, cross-tied bus, battery reserve | Near-impossible total power loss scenario |

## **1.2  Propulsion Architecture**

| CORE | Two small ICE engines (generator duty only, fixed RPM) feed two independent electrical buses. Each bus powers one contra-rotating rim-drive motor on the tail boom. A solid-state battery buffer covers peak demand and provides 10+ minute emergency reserve. Cross-tied bus allows any single component failure to be absorbed without loss of propulsion. |
| :---: | :---- |

| GENERATOR AICE \+ Gen\~60 HP | BATTERY BUFFER3–5 kWh10 min reserve | RIM MOTOR 1Fwd stageClockwise | RIM MOTOR 2Aft stageCounter-CW |
| :---: | :---: | :---: | :---: |

*Generator B mirrors Generator A on independent bus. Cross-tie normally open, closes automatically on any single system fault.*

# **2 — Risk Register & Sequencing Rationale**

Work is sequenced highest-risk first. A validated propulsion system is the prerequisite for all other major commitments. A beautiful airframe built around an unproven drivetrain is an expensive mistake.

| Risk Item | Probability | Impact | Sequence | Mitigation |
| :---- | :---- | :---- | :---- | :---- |
| **Series hybrid propulsion** | HIGH | **CRITICAL** | **1 — FIRST** | Benchtop → ground test → flight test as hard gates |
| **Rim-drive motor availability** | MEDIUM — Donut Lab unverified; alternatives exist | HIGH | **1 — CONCURRENT** | Identify 3+ alternative ring motor suppliers before committing |
| **Generator ECU altitude compensation** | MEDIUM — motorcycle ECU not mapped above 12,000 ft | MEDIUM | **1 — EARLY** | Custom Speeduino with wideband O2 closed-loop control |
| **Wing integral fuel tank sealing** | LOW-MEDIUM — proven method (DA40), requires discipline | MEDIUM | 3 — after structure | ProSeal process, pressure test before closing skin |
| **Whole-aircraft parachute integration** | LOW — BRS proven in EAB category | MEDIUM | 4 — systems phase | Standard BRS installation, canister location reserved from day 1 |
| **FAA Experimental documentation** | LOW — well-understood EAB process | LOW | Ongoing | EAA technical counselor engaged early, 51% tracked from start |

# **3 — Project Phases**

Six phases with hard gates between each. No phase begins until the previous gate is met. Propulsion validation gates everything downstream.

| PHASE 0  ·  FOUNDATION & PROPULSION CONCEPT   |   Months 1–4 *Gate: Propulsion architecture selected, key suppliers identified, AI team infrastructure operational* |
| :---- |
| • Propulsion Team stood up — AI research agents activated • Survey all rim-drive / ring motor suppliers — minimum 3 viable alternatives to Donut Lab identified • Generator engine candidates benchmarked — Honda CBR300, CBR600, Kawasaki equivalents • Custom ECU architecture selected — Speeduino or equivalent, altitude compensation strategy confirmed • Donut Lab partnership evaluation — contact initiated only if Verge motorcycle deliveries verified • MAOS-PROP-001: Propulsion Architecture Selection Document signed off before any hardware purchased • Project Git repository established, all MAOS documents committed, teams onboarded • EAA technical counselor identified and engaged |

| PHASE 1  ·  PROPULSION BENCHTOP VALIDATION   |   Months 3–10 *Gate: Generator \+ motor \+ inverter system produces target power, sustains 2-hour run, survives simulated failure* |
| :---- |
| • Generator A benchtop: ICE engine coupled to permanent magnet generator — power output measured • ECU altitude simulation: intake pressure simulation to 20,000 ft equivalent — closed-loop mixture confirmed • Rim-drive motor benchtop: selected motor at target RPM under load — thermal, efficiency, vibration measured • Bus cross-tie test: simulate Generator A failure — confirm automatic bus tie and sustained operation on B • Battery buffer integration: charge/discharge cycle under simulated climb demand — 3 kWh covers takeoff gap • 2-hour continuous run at cruise power setting — no degradation, temperatures stable • Vibration signature measured — confirm contra-rotation torque cancellation • MAOS-PROP-TEST-001: Benchtop Validation Report signed off before ground test begins |

| PHASE 2  ·  AIRFRAME DESIGN & ANALYSIS   |   Months 4–14  (concurrent with Phase 1 after month 4\) *Gate: Aerodynamic model frozen, structures sized, weight budget closed within 5% of target* |
| :---- |
| • XFLR5 viscous analysis — Riblett GA35-615 airfoil, CLmax and stall speed validated • AVL stability analysis — tail surfaces sized, boom length confirmed, static margin verified • CG calculation closed — all major mass items located on station map • Wing spar sizing confirmed — aluminum tube, fuel volume verified against mission requirement • Structural analysis: spar, spar saddle, boom attach, generator mount — all critical joints documented • Weight budget closed: target 1,230 lbs empty, 2,430 lbs gross • FreeCAD models: spar saddle, boom attach flange, generator mount, rim motor mounts • DXF files prepared for SendCutSend: all flat-cut aluminum parts |

| PHASE 3  ·  PROPULSION GROUND TEST & AIRFRAME BUILD   |   Months 10–24 *Gate: Propulsion system ground-tested in airframe. Airframe structurally complete.* |
| :---- |
| • Propulsion system installed in ground test rig — full airframe loads simulated • Throttle response, failure simulation, emergency bus-tie tested at full power • Pod primary structure complete — frames, floor, skin, spar saddle installed • One-piece wing built — spar installed, ribs, skin, fuel tanks sealed and pressure-tested • Tail boom fabricated — aluminum tube with motor mount rings and stabilizer attach • Rim-drive motors installed on boom — alignment, clearance, prop track verified • Control system rigged — all surfaces, cables, pushrods • Ground run \#1: taxi test, prop track, vibration check, thermal survey • Phase 3 gate: DAR structural inspection before closing |

| PHASE 4  ·  SYSTEMS INTEGRATION & FIRST FLIGHT PREP   |   Months 22–30 *Gate: Aircraft airworthy. All systems functional. Phase 1 flight test plan approved.* |
| :---- |
| • Avionics installed — Garmin G3X or equivalent, IFR capable • Power management system integrated — generator control, battery BMS, motor controllers unified • TKS ice protection installed — wings, windscreen, prop anti-ice (resistive blade elements) • Whole-aircraft parachute installed and rigged • Weight and balance confirmed — actual weighing • DAR inspection — Experimental certificate issued • First flight crew briefing — abort criteria, emergency procedures, chase aircraft |

| PHASE 5  ·  FLIGHT TEST & ENVELOPE EXPANSION   |   Months 30–40 *Gate: 40-hour Phase 1 complete. Aircraft released to full operating envelope.* |
| :---- |
| • Phase 1: 25 nm radius, pilot only, VMC only — basic airworthiness • Stall series: clean and configured — confirm root-first stall behavior • Generator failure simulation in flight: confirm battery sustains controlled flight to landing • Single motor failure: confirm manageable asymmetric torque, controlled flight maintained • Climb performance: full power at altitude, generator/battery behavior during climb verified • Cruise efficiency: fuel flow, power output, L/D validation against predictions • IFR systems checkout: autopilot, nav, ice protection activation • Phase 1 complete at 40 hours; Phase 2 begins: IFR, cross-country, full useful load |

# **4 — Team Structure**

Six functional teams plus an Integration lead. Each team pairs a human lead with AI agents in a defined role. Teams are small by design — one or two humans plus AI agents is the target. The AI agents do not replace human judgment on safety-critical decisions. They eliminate the research, documentation, analysis, and iteration burden that consumes most of a builder's time.

| AI PRINCIPLE | Agents handle: search, synthesis, simulation loops, documentation generation, BOM research, first-pass analysis, and compliance tracking. Humans own: all safety decisions, all sign-offs, all physical builds, all test conduct, and all regulatory submissions. The agent is the crew chief who has read everything and forgotten nothing. The human is the pilot-in-command. |
| :---: | :---- |

| 01 | TEAM 01: PROPULSION *Design, build, and validate the complete series hybrid drivetrain before any other major commitment is made.* |  |
| ----- | :---- | :---- |
| **TEAM LEAD** Project Lead / Systems Engineer | **AI AGENT ROLE** Motor survey agent monitors supplier announcements continuously. ECU mapping agent runs altitude simulation tables. Power budget agent models generator/battery interaction across full flight envelope. FMEA agent generates failure mode analysis automatically from system descriptions. | **HUMAN CONTRIBUTORS** • Mechanical / electrical engineer • Embedded systems developer (custom ECU) • EAA technical counselor (advisory) |
| **KEY DELIVERABLES** • MAOS-PROP-001: Architecture selection • Motor supplier matrix — 5+ candidates • Generator engine test report • ECU altitude compensation validation • 2-hour benchtop run report • FMEA — complete failure mode analysis | **RISK ITEMS** • Rim-drive motor availability / timeline • ECU altitude tables above 12,000 ft • Generator thermal management buried in wing • Bus cross-tie response time validation |  |

| 02 | TEAM 02: AERODYNAMICS & PERFORMANCE *Validate the aerodynamic model, size the tail, confirm stall safety, and close the performance budget.* |  |
| ----- | :---- | :---- |
| **TEAM LEAD** Aeronautical Engineer / Pilot | **AI AGENT ROLE** XFLR5 automation agent runs airfoil parameter sweeps and formats results. AVL agent iterates tail volume coefficients to hit stability targets. Performance agent builds flight envelope charts from analysis outputs. OpenVSP agent maintains geometry model as design changes propagate. | **HUMAN CONTRIBUTORS** • Pilot (operational requirements ownership) • Aeronautical engineer or EAA technical counselor |
| **KEY DELIVERABLES** • MAOS-AERO-002: XFLR5 viscous results • MAOS-AERO-003: AVL stability report • Tail surface sizing — boom length confirmed • CLmax and stall speed validated • Preliminary performance manual | **RISK ITEMS** • Riblett airfoil CLmax confirmation • Static margin with aft CG loading • Tail volume adequacy with short boom |  |

| 03 | TEAM 03: STRUCTURES *Size all primary structure, produce fabrication drawings, and deliver a buildable kit of flat-cut parts.* |  |
| ----- | :---- | :---- |
| **TEAM LEAD** Structural Engineer / Builder | **AI AGENT ROLE** FreeCAD automation agent converts analysis outputs to parametric models. DXF agent prepares SendCutSend-ready files and cut lists. Weight agent tracks every component against budget in real time. BOM agent cross-references Aircraft Spruce and McMaster-Carr for pricing and availability. | **HUMAN CONTRIBUTORS** • Builder with composites and aluminum experience • Structural engineer (advisory, critical joints) |
| **KEY DELIVERABLES** • Wing spar analysis and sizing • Spar saddle detail design • Boom attach flange • Generator mount design • Rim motor mount rings • Full DXF package for SendCutSend • Weight budget — closed to 5% | **RISK ITEMS** • Spar tube sizing vs. fuel volume tradeoff • Boom tensile loads from dual motor thrust • Generator mount vibration isolation design |  |

| 04 | TEAM 04: SYSTEMS & AVIONICS *Design and integrate all aircraft systems: electrical, avionics, ice protection, parachute, and power management.* |  |
| ----- | :---- | :---- |
| **TEAM LEAD** Systems / Avionics Engineer | **AI AGENT ROLE** Wiring diagram agent generates interconnect diagrams from system descriptions. Regulatory agent cross-references FAA AC 43.13 and EAB guidance. Power load agent calculates bus loads across all operational modes. IFR compliance agent tracks avionics requirements against intended operation. | **HUMAN CONTRIBUTORS** • Avionics installer / A\&P (advisory) • Electrical engineer • Software developer (power management ECU) |
| **KEY DELIVERABLES** • Electrical architecture document • Power management software spec • Avionics installation plan • Ice protection system design • Parachute integration • Wiring diagrams — complete | **RISK ITEMS** • Power management software validation • Failure detection and bus-tie response logic • Prop anti-ice slip ring design and reliability |  |

| 05 | TEAM 05: TRAILER & GROUND SUPPORT *Design and build the trailer system as a co-equal component: transport, deployment, charging infrastructure, maintenance support.* |  |
| ----- | :---- | :---- |
| **TEAM LEAD** Mechanical / Integration Engineer | **AI AGENT ROLE** Structural agent sizes trailer frame for aircraft transport loads. Crane geometry agent optimizes lift point for one-person operation. Solar layout agent calculates panel area vs. charging rate. Logistics agent tracks component sourcing, lead times, and total system cost. | **HUMAN CONTRIBUTORS** • Fabricator / welder • Electrician (shore power and solar systems) |
| **KEY DELIVERABLES** • Trailer structural design • Crane system — one-person 37-ft wing lift • Shore power inlet — 50A/240V • Solar panel mounting provision • Battery charging infrastructure provision • Deployment procedure — target 45 minutes | **RISK ITEMS** • Crane counterbalance with one-piece wing • Road legal dimensions and weight limits • Shore power compatibility across airstrip types |  |

| 06 | TEAM 06: DOCUMENTATION & REGULATORY *Maintain 51% compliance record, produce all required documentation, and manage the path to Experimental certificate.* |  |
| ----- | :---- | :---- |
| **TEAM LEAD** Documentation & Compliance Lead | **AI AGENT ROLE** Regulatory agent monitors FAA policy updates and flags relevant changes. 51% compliance agent tracks builder hours against the rule in real time. Documentation agent converts engineering notes and test results into formal document format. Decision log agent captures every major design choice with rationale automatically. | **HUMAN CONTRIBUTORS** • Project lead (document owner) • EAA technical counselor • DAR (Designated Airworthiness Representative) |
| **KEY DELIVERABLES** • Builder log — continuous from day 1 • 51% compliance matrix • Design decision log • Operating Limitations draft • Flight manual preliminary • Experimental certificate package | **RISK ITEMS** • 51% rule interpretation for novel power systems • Generator engine approval pathway • Documenting AI-assisted design decisions for compliance |  |

# **5 — Agentic AI Architecture**

The AI architecture is designed around one principle: agents eliminate the overhead that kills homebuilt projects. Most airplane projects die not from lack of skill but from the accumulated weight of undone research, unwritten documents, and untracked decisions. Agents handle that entire category of work.

## **5.1  Agent Categories**

| Agent Type | Function | Tools | Human Oversight |
| :---- | :---- | :---- | :---- |
| **Research Agents** | Monitor technical literature, supplier announcements, regulatory updates, and test results | Web search, document indexing, summarization | Weekly briefing review — human approves action items |
| **Analysis Agents** | Run parametric loops in XFLR5, AVL, OpenVSP. Format results. Flag anomalies. Propose next step. | XFLR5 scripting, AVL input files, OpenVSP Python API | Human reviews all conclusions before they inform design |
| **Documentation Agents** | Convert engineering discussions and test data into formatted documents. Maintain decision log. Update BOM. | Document templates, spreadsheet, Git commits | Human reviews and signs off all released documents |
| **Design Agents** | Iterate parametric CAD models, generate DXF files, track weight against budget as geometry changes | FreeCAD Python API, DXF export, weight spreadsheet | Human approves all geometry changes affecting performance or structure |
| **Compliance Agents** | Track 51% builder hours, monitor FAA regulatory database, maintain inspection readiness checklist | FAA database queries, hour tracking, document cross-reference | Human owns all regulatory submissions and sign-offs |
| **Supplier Agents** | Monitor Aircraft Spruce, McMaster-Carr, SendCutSend pricing. Alert on lead time changes. Maintain live BOM cost. | Web queries, BOM spreadsheet, alerts | Human approves all purchases |

## **5.2  Infrastructure**

| Component | Implementation | Est. Monthly Cost |
| :---- | :---- | :---- |
| AI model | Claude API — claude-sonnet, per-token billing | $50–200 at active development pace |
| Orchestration | Python scripts — open source, stored in /tools in project repo | $0 — builder writes and owns |
| Document store | Git repository — all docs, analysis files, decisions in version control | $0 — GitHub free tier |
| Analysis tools | XFLR5, AVL, OpenVSP — all open source, all scriptable | $0 |
| CAD | FreeCAD with Python API — all files in STEP/DXF open formats | $0 |
| BOM tracking | CSV files in Git — agent reads and writes directly | $0 |

## **5.3  Phase 0 Propulsion Agent Priorities**

Since propulsion is the first priority, the following agents activate in the first week:

| Agent | Immediate Task | Output | Cadence |
| :---- | :---- | :---- | :---- |
| **Motor Survey** | Search and catalog all rim-drive / ring motor / axial flux motor suppliers at 100–200 kW suitable for aviation | Supplier matrix with specs, pricing, aviation precedent | Weekly refresh |
| **Donut Lab Monitor** | Track Verge Motorcycle delivery reports, VTT independent test results, aviation partnership announcements | Weekly go/no-go recommendation on partnership timing | Daily scan |
| **Generator Engine** | Survey motorcycle and small auto engines 60–120 HP range. Research aircraft conversion history. Identify ECU options. | Engine candidate matrix with weight, cost, conversion history | Monthly refresh |
| **FMEA** | Build failure mode analysis from propulsion architecture description. Identify single-point failures. Propose mitigations. | Initial FMEA document updated as design evolves | On arch change |
| **Power Budget** | Model generator output vs demand across full flight envelope at sea level and 20,000 ft. Size battery buffer. | Power flow charts: cruise, climb, takeoff, emergency modes | On param change |

# **6 — Immediate Next Steps**

Phase 0 begins now. These actions are sequenced for the first 30 days, executable by one person with AI agent support.

| Priority | Action | AI Support | Timeline |
| :---- | :---- | :---- | :---- |
| **1 — THIS WEEK** | Activate Motor Survey Agent. Generate initial rim-drive supplier matrix with 5+ candidates beyond Donut Lab. | Research agent — web search, spec compilation | Days 1–5 |
| **2 — THIS WEEK** | Activate Donut Lab Monitor. Establish baseline — what has been independently verified as of today. | Research agent — Electrek, VTT reports, Verge delivery tracking | Days 1–5 |
| **3 — WEEK 2** | Generator engine candidate list: Honda CBR300, CBR600, Kawasaki equivalents. Weight, cost, conversion history. | Research agent — EAA forums, aircraft conversion databases | Days 7–14 |
| **4 — WEEK 2** | Speeduino ECU evaluation. Confirm altitude compensation via closed-loop wideband O2. Identify hardware config. | Technical research agent | Days 7–14 |
| **5 — WEEK 3** | MAOS-PROP-001 first draft: propulsion architecture selection document with all candidates and recommendation. | Documentation agent formats from engineering discussion | Days 14–21 |
| **6 — WEEK 4** | Establish project Git repository. All existing MAOS documents committed. All team members onboarded. | Documentation agent organizes existing files | Days 14–28 |
| **7 — MONTH 2** | XFLR5 installed. Riblett GA35-615 airfoil loaded. Viscous analysis run. CLmax confirmed. | Analysis agent — XFLR5 scripting, result formatting | Days 28–45 |
| **8 — MONTH 2** | EAA technical counselor identified. First meeting. 51% compliance tracking initialized. | Compliance agent — hour tracking initialized | Days 28–60 |

***The airplane that wants to be built.***

*Every major design decision in this project has reinforced the previous ones. The series hybrid architecture makes the trailer infrastructure more valuable. The rim-drive makes contra-rotation natural. The contra-rotation makes redundancy elegant. The battery buffer makes the generator altitude limitation irrelevant. This is what convergent design feels like. Proceed.*

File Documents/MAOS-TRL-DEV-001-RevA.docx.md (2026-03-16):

**MAOS**

Mobile Aviation Operating System

**Trailer and Ground Support System**

**Development Plan**

Document: MAOS-TRL-DEV-001

Revision: A (Initial Draft)

Date: March 12, 2026

**Status: DRAFT — Pre-Decisional**

# **Introduction**

## **Purpose**

This document defines the development plan for the MAOS aircraft trailer and ground support system. The trailer serves four integrated functions: road transport of the disassembled aircraft, field deployment and recovery via an integrated crane, mobile workshop for maintenance and repair, and ground power and charging infrastructure for the aircraft systems.

The trailer is not an afterthought to be designed once the aircraft is complete. Key aircraft design decisions, particularly wingspan, wing attachment geometry, and boom configuration, are directly coupled to trailer dimensions, crane loads, and road-legal compliance. This plan recognizes that coupling and structures the development to resolve the interdependencies in the correct order.

## **Scope**

This plan covers the full trailer system from requirements definition through integration testing. It does not cover aircraft design decisions in detail, but identifies the specific aircraft parameters that must be locked before trailer work can proceed, and documents the interfaces between the two systems.

## **Design Philosophy**

The trailer development follows the same principles as the aircraft program:

* Start with a commercial off-the-shelf (COTS) enclosed gooseneck trailer as the base platform. Do not build a trailer from scratch.

* Minimize custom fabrication. Buy the rolling chassis, suspension, brakes, DOT lighting, and weatherproofing. Customize only the parts unique to the aircraft mission.

* Design for single-person operation. Every step of the deployment and recovery sequence must be achievable by one person without external assistance.

* The trailer must be road-legal in Texas without special permits under normal operating conditions. Wing tip overhang with proper flagging is acceptable.

* Weight matters on the trailer too. Every pound of trailer structure is a pound subtracted from useful payload or added to tow vehicle demand.

## **Reference Documents**

* MAOS-GA-001: General arrangement concept rendering

* MAOS-ECS-DEV-001 Rev B: Environmental control system development plan

* Texas Transportation Code, Chapter 621: Vehicle size and weight limits

* TxDMV Size/Weight Limits (txdmv.gov)

* FMVSS 108: Lamps, reflective devices, and associated equipment

# **Aircraft Interface Requirements**

The following aircraft parameters drive trailer design. Parameters marked TBD are open decision gates that must be resolved in Phase 0 before trailer procurement.

| Parameter | Current Value | Impact on Trailer |
| :---- | :---- | :---- |
| **Wingspan** | **TBD (est. 32–38 ft)** | Sets trailer length, wing overhang, crane extension, and rotation clearance envelope |
| **Wing assembly dry weight** | **TBD (est. 250–400 lbs)** | Sizes crane beam, hoist, trolley, and counterweight. Includes structure, two Honda 400cc generators, coolant, TKS, and plumbing. |
| **Wing attachment type** | Single-piece, lifts off as one unit | Crane lifts full wing from spar carry-through. Single lift point near root CG. |
| **Wing root chord** | **TBD (est. 54–72 in)** | Sets wing storage channel width in trailer roof |
| **Pod dimensions** | 52"W × 58"H × 156"L | Pod fits within 8.5 ft trailer width. Floor loading and tie-down locations. |
| **Boom length** | **TBD (est. 9–13 ft)** | Total fuselage length (pod \+ boom) determines floor space and trailer length requirement |
| **Boom attachment** | **TBD: stays attached or detaches** | If attached: trailer stores 22–25 ft fuselage. If detachable: separate stowage required. |
| **Tail configuration** | Conventional (not T-tail) | Tail surfaces at boom end must clear trailer interior or fold for stowage |
| **Propulsion motors** | Rim-drive on boom (Donut Motor or Beyond Motors AXM2) | Motors are on boom, not in wing. Reduces wing weight, simplifies crane loads. |
| **Generators** | 2× Honda 400cc (\~50–60 lbs each) | Mounted in wing. Much lighter than Kawasaki alternative. Generators are protected under roof during transport. |
| **Flight battery capacity** | **TBD** | Determines ground charging power requirement and trailer electrical system sizing |
| **Gross weight** | **TBD (est. 2,600–3,200 lbs)** | Affects trailer GVWR selection and tow vehicle requirement |
| **Flap configuration** | **TBD: flapless under consideration** | Flapless increases required wing area and span by 3–5 ft, directly affecting trailer length and overhang |

**Note:** Red-highlighted values are open decision gates. These must be resolved before the trailer COTS selection in Phase 1A. The flaps decision is especially impactful: going flapless adds approximately 3–5 feet of wingspan, which cascades through every trailer dimension.

# **Road-Legal Envelope**

## **Texas Size Limits (Without Permit)**

| Dimension | Texas Legal Limit | MAOS Implication |
| :---- | :---- | :---- |
| **Width** | 8 ft 6 in (102 in) | Standard 8.5 ft trailer is at limit. Wing chord must fit within this during transport. |
| **Height** | 14 ft | Critical constraint. Trailer floor (\~18 in) \+ interior height (\~90 in) \+ wing thickness (\~12 in) \+ crane beam (\~10 in) \= \~130 in (10 ft 10 in). Margin exists but must be verified. |
| **Combination length** | 65 ft (truck \+ trailer) | Tow vehicle \~20 ft \+ 32 ft trailer \+ 6 ft wing overhang \= 58 ft. Within limit. |
| **Rear overhang** | 4 ft without flag; greater with red flag/light | Wing tips extend past trailer rear. Flag/light required if overhang exceeds 4 ft. Tips are expendable composite structure; generators are protected inboard. |

## **Height Budget Detail**

The 14-foot height limit is the tightest constraint and must be tracked carefully through design:

| Component | Height (in) | Running Total (in) |
| :---- | :---- | :---- |
| Ground to trailer floor (tires \+ suspension \+ frame) | 18–22 | 18–22 |
| Interior height (standard car hauler) | 84–90 | 102–112 |
| Roof structure | 2–3 | 104–115 |
| Wing storage channel (wing thickness at root \+ padding) | 14–18 | 118–133 |
| Crane beam \+ trolley \+ hardware | 8–12 | 126–145 |
| **14 ft limit** | **168** | **23–42 in margin** |

The margin appears comfortable but depends heavily on actual trailer floor height and wing root thickness. A low-deck trailer design or drop-axle configuration would increase margin. This must be verified with the actual COTS trailer selected.

## **Tow Vehicle Requirements**

A gooseneck trailer in the 28–32 ft, 14,000 lb GVWR class requires a 3/4-ton or 1-ton pickup truck (e.g., Ford F-250/350, Ram 2500/3500, Chevrolet 2500/3500). The truck must have a gooseneck hitch rated for the loaded trailer weight and a combined GCWR sufficient for the total combination. Estimated loaded trailer weight: trailer empty (\~4,500 lbs) \+ aircraft (\~2,800 lbs) \+ tools/equipment (\~500 lbs) \= \~7,800 lbs, well within the 14,000 lb GVWR.

# **COTS Trailer Baseline**

## **Recommended Base Platform**

The recommended starting point is a standard enclosed gooseneck car hauler trailer in the 8.5 ft × 28–32 ft size class. This is a mature, high-volume market segment with dozens of manufacturers and well-understood construction practices.

### **Minimum Specifications for COTS Selection**

* Exterior width: 8 ft 6 in (102 in) maximum (at Texas legal limit)

* Box length: 28–32 ft (determined by Phase 0A wingspan decision)

* Interior height: 7 ft 6 in minimum (90 in)

* Frame: Aluminum preferred for weight savings; steel acceptable at lower cost

* Axles: Tandem 7,000 lb torsion axles with electric brakes (14,000 lb GVWR)

* Hitch: Gooseneck coupler (not 5th wheel)

* Rear door: Ramp door (for aircraft roll-on if needed) or barn doors

* Side door: 36 in minimum entry door

* Electrical: Basic 7-way connector; 110V package optional (will be replaced in Phase 3\)

* Roof: Standard construction; will be modified in Phase 2

* Interior: Minimal finish (plywood walls acceptable; will be refinished)

### **Candidate Manufacturers**

Preliminary candidate list (not exhaustive, to be refined during Phase 1A):

* Featherlite (all-aluminum, premium, higher cost)

* CargoPro / Mission (aluminum frame, good value)

* Rock Solid Cargo (steel and aluminum options, wide size range)

* MO Great Dane / Total Trailers (custom builds with workshop options including roof-mounted crane and compressor)

* Millennium Trailers (custom gooseneck builds, motorsport focus)

### **Budget Estimate**

| Item | Low Estimate | High Estimate |
| :---- | :---- | :---- |
| COTS trailer (steel frame, basic) | $15,000 | $22,000 |
| COTS trailer (aluminum frame) | $22,000 | $35,000 |
| Crane system materials | $2,000 | $5,000 |
| Electrical system (battery, inverter, wiring) | $3,000 | $8,000 |
| Air compressor and plumbing | $400 | $800 |
| Workshop fit-out (bench, cabinets, lighting) | $1,500 | $3,000 |
| DOT compliance modifications | $300 | $800 |
| **Total estimated range** | **$22,200** | **$54,600** |

The electrical system cost range is wide because the aircraft charging decision (Phase 3A) determines whether this is a 2 kW tool-power system or a 10–15 kW aircraft-charging system. Resolve early.

# **Development Phases**

The following phases are sequenced to resolve dependencies in the correct order. Phases marked as parallelizable can overlap in time. Decision gates must be resolved before dependent phases proceed.

## **Phase 0: Requirements Lock**

Nothing is purchased or fabricated until Phase 0 is complete. These are decisions, not hardware.

| 0A | Aircraft Geometry Freeze |
| ----- | :---- |
| **Scope** | Lock wingspan, pod+boom total length, wing root chord, wing attach point location (distance aft of pod nose), wing dry weight estimate, V-strut attach geometry, and spar carry-through dimensions. The flaps/flapless decision must be resolved here as it directly affects wingspan. All trailer dimensions derive from these numbers. |
| **Flags** | **DECISION GATE**  **GATE: Wingspan decided**  **GATE: Boom attach/detach decided**  **GATE: Flaps/flapless decided** |
| **Outputs** | Aircraft external dimensions drawing (3-view), wing weight budget with component breakdown, wing attach fitting preliminary design, CG envelope for wing-on and wing-off loading conditions |

| 0B | Road-Legal Envelope Verification |
| ----- | :---- |
| **Scope** | Confirm all Texas size/weight limits against the aircraft geometry from Phase 0A. Determine wing-tip overhang length and required flagging/lighting. Confirm tow vehicle selection and verify GCWR is sufficient. Verify height budget with estimated trailer and crane dimensions. Contact TxDMV if any dimension is ambiguous. |
| **Flags** | **Depends on 0A**  **External: TxDMV** |
| **Outputs** | Legal envelope summary document, tow vehicle selection with GCWR verification, overhang flagging/lighting specification, height budget calculation |

| 0C | Operational Concept of Use (CONOPS) |
| ----- | :---- |
| **Scope** | Write the complete deployment and recovery sequence, step by step, with time estimates. Cover: normal deployment (trailer to flight-ready), normal recovery (taxi to road-ready), degraded-mode operations (rain, wind, darkness, equipment failure), abort procedures (what happens if crane jams mid-lift, if wing binds in storage channel, if wind gust catches wing during rotation). Every step must be achievable by a single operator. This document drives all subsequent design decisions and is the acceptance test for Phase 5\. |
| **Flags** | **Depends on 0A, 0B** |
| **Outputs** | CONOPS document with illustrated step-by-step sequences, time budget per step, single-operator verification analysis, abort/contingency procedures, environmental operating limits |

## **Phase 1: Base Trailer Procurement**

| 1A | COTS Trailer Selection and Order |
| ----- | :---- |
| **Scope** | Using the locked geometry from Phase 0A and legal envelope from Phase 0B, select the optimal COTS enclosed gooseneck trailer. Key decision: aluminum vs steel frame (weight vs cost). Request manufacturer drawings and structural details before ordering. Order with minimal interior finish; the interior will be rebuilt. Consider requesting the trailer without a standard roof if the manufacturer supports this, as the roof will be heavily modified. Typical lead time is 8–16 weeks for a custom gooseneck order. |
| **Flags** | **Depends on 0A, 0B**  **External: Trailer manufacturer** |
| **Outputs** | Purchase order with specifications, manufacturer structural drawings, delivery timeline, inspection checklist for delivery acceptance |

| 1B | Structural Survey and CAD Model |
| ----- | :---- |
| **Scope** | Upon trailer delivery, survey all actual dimensions: frame member sizes, cross-sections, and locations; roof truss spacing and member sizes; axle positions; floor structure; wall framing. Build a complete CAD model of the as-received trailer in FreeCAD (STEP export). Identify structural load paths and determine where roof modifications can be made without compromising the frame. The roof on most enclosed trailers is a stressed-skin panel that contributes to torsional rigidity; cutting it requires compensating structure. |
| **Flags** | **Depends on 1A delivery** |
| **Outputs** | As-built CAD model (FreeCAD/STEP), structural member map with cross-sections, roof modification feasibility analysis including required reinforcement |

## **Phase 2: Crane and Wing Storage System**

This is the most technically challenging phase. The crane system must safely lift, rotate, and stow the wing assembly, and the roof modification must maintain trailer structural integrity while creating a weatherproof wing storage channel.

| 2A | Crane Beam and Trolley Design |
| ----- | :---- |
| **Scope** | Design the longitudinal I-beam (or box beam), vertical support columns tying into the trailer main frame (not just the roof), traveling trolley with hoist mechanism, and the rearward extension beyond the trailer end. The beam must cantilever approximately 5–6 feet past the trailer rear to reach the wing attach fittings when the aircraft is parked nose-to-trailer. Design the swivel/rotation bearing at the hoist point to allow controlled 90-degree wing rotation. Specify electric winch (preferred for single-person operation) or manual come-along. Design the wing cradle/sling that interfaces with the wing spar carry-through or dedicated lift fittings on the wing. Safety factor: 2.0× on wing dry weight for all structural members. Include analysis for dynamic loads during rotation (wind gust on half-span wing acting as a sail). |
| **Flags** | **Depends on 0A, 1B**  **DECISION GATE** |
| **Outputs** | Crane assembly design drawings, beam stress analysis (hand calcs and/or FEA), trolley and hoist specification, swivel bearing specification, wing cradle design with interface to wing fittings, dynamic load analysis for rotation in wind, load test plan |

| 2B | Roof Modification and Wing Storage Channel |
| ----- | :---- |
| **Scope** | Design the roof opening, wing storage rails, and weather protection system. The wing slides into the roof space parallel to the trailer length (chord-wise, leading edge forward) and rests on padded rails. Channel width must accommodate the root chord plus clearance for V-struts (if stowed attached) or just the bare wing (if struts detach first). Provide structural reinforcement to compensate for the roof material removed. Design a weather protection system: options include hinged roof panels that close over the wing, a fitted tarp/cover with tie-downs, or a sliding roof section. The system must be operable by one person. |
| **Flags** | **Depends on 1B, 2A**  **GATE: V-struts on or off during stow?** |
| **Outputs** | Roof modification drawings with reinforcement details, wing rail and cradle design, weather protection system design, structural analysis of modified roof |

| 2C | Fabrication and Load Testing |
| ----- | :---- |
| **Scope** | Build the crane system, execute the roof modification, and install wing storage rails. Conduct load testing with a sandbag dummy wing at 1.5× design load before lifting the real wing. Perform the full deployment and recovery sequence with the dummy load, measuring time per step against the CONOPS targets from Phase 0C. Iterate on any element that binds, jams, interferes, or takes too long. This phase ends when the crane system passes load testing and the dummy-wing deployment sequence meets CONOPS time targets. |
| **Flags** | **Depends on 2A, 2B** |
| **Outputs** | Completed crane and roof installation, load test report with photographs, deployment/recovery time-motion study vs CONOPS targets, punch list of items requiring iteration |

## **Phase 3: Workshop and Support Systems**

Phases 3A through 3C can begin design work in parallel with Phase 2, but installation must wait until Phase 2 roof modifications are complete (to avoid rework). Design work can proceed using the CAD model from Phase 1B.

| 3A | Electrical System |
| ----- | :---- |
| **Scope** | Design the complete trailer electrical system. Shore power inlet: 30A (TT-30, common at campgrounds) or 50A (14-50, common at RV parks). Battery bank: LiFePO4 chemistry for weight savings and deep-cycle tolerance. Inverter/charger: pure sine wave, sized for peak tool loads and aircraft charging if applicable. DC distribution panel with circuit protection. LED interior work lighting (high CRI for maintenance tasks) and exterior ground lighting for night operations. 120V GFCI outlets at workbench and rear door. USB outlets for devices. Decision gate: will the trailer electrical system charge the aircraft flight battery? If yes, the system scales from approximately 3 kW (tools and lights only) to 10–15 kW (aircraft charging), which fundamentally changes battery bank size, wire gauge, shore power requirements, and cost. |
| **Flags** | **Can run in parallel**  **DECISION GATE**  **GATE: Aircraft charging from trailer?** |
| **Outputs** | Single-line electrical diagram, load analysis for all operating modes, component specification list with sources, wire routing plan on CAD model, shore power interface specification |

| 3B | Compressed Air System |
| ----- | :---- |
| **Scope** | Install a small, quiet air compressor permanently mounted with vibration isolation. Primary uses: tire inflation, dust removal, pneumatic rivet gun (if used in assembly). The compressor does not need to sustain continuous air tool operation; modern cordless tools handle most tasks. Recommended: California Air Tools or equivalent ultra-quiet oil-free compressor, 1–2 HP, 4–8 gallon tank. Plumb to quick-disconnect fittings at workbench area and at rear door. Consider supplementing with a CO2 bottle for portable high-volume inflation (tire service away from trailer). |
| **Flags** | **Can run in parallel** |
| **Outputs** | Compressor specification with mounting design, air line routing plan, quick-disconnect locations, vibration isolation detail |

| 3C | Interior Layout and Tool Storage |
| ----- | :---- |
| **Scope** | Design the interior arrangement accounting for the pod+boom sitting on the trailer floor and the wing stowed overhead. Key elements: workbench (folding or fixed, along one side wall), tool cabinets or wall-mounted panels, spare parts storage bins, wing stand fixtures (for working on the wing when it is removed but not yet on the aircraft), consumables storage (TKS fluid, coolant, oil), fire extinguisher (dry chemical, accessible from both interior and exterior), and first aid kit. The interior must allow maintenance access to the aircraft while stowed. The layout must not interfere with the crane operation or the wing insertion path. |
| **Flags** | **Depends on 1B**  **Can run in parallel** |
| **Outputs** | Interior layout drawings on CAD model, workbench design, cabinet and storage design with tool inventory list, maintenance access analysis showing reach to critical aircraft service points |

## **Phase 4: Road Compliance and Safety**

| 4A | DOT Lighting and Safety Compliance |
| ----- | :---- |
| **Scope** | The COTS trailer arrives DOT-compliant, but modifications (crane structure above roofline, wing overhang at rear) change the vehicle profile and may require additional lighting. Verify: rear clearance and stop lights are visible with wing stowed, clearance/marker lights are installed on crane structure if it projects above the original roofline, reflective conspicuity tape is applied to any new structural elements visible from the sides or rear, breakaway brake system remains functional after all modifications. For transport with wing overhang: red flag (minimum 12 in square, daytime) and red light (nighttime) on each wing tip. |
| **Flags** | **Depends on 2C**  **External: DOT inspection** |
| **Outputs** | Lighting modification plan, DOT compliance checklist, reflective tape placement diagram, wing-tip flag/light specification, inspection scheduling |

| 4B | Weight Distribution and Towing Dynamics |
| ----- | :---- |
| **Scope** | Calculate loaded trailer CG and verify: tongue weight is 10–15% of total loaded trailer weight (gooseneck standard), axle loads do not exceed rated capacity, total combination weight is within tow vehicle GCWR. The trailer CG shifts significantly depending on pod position on the floor versus wing position on the roof; produce a loading diagram showing the correct pod placement for each loading condition (wing-on, wing-off, empty). Conduct road test: highway stability at legal speed, braking distances (loaded and unloaded), backing maneuvers through typical airport gate, fuel consumption impact on tow vehicle. |
| **Flags** | **Depends on 2C** |
| **Outputs** | Weight and balance calculation with CG diagram, loading checklist for correct pod placement, tow test report with stability assessment, braking distance measurements |

| 4C | Insurance and Registration |
| ----- | :---- |
| **Scope** | Register the modified trailer with TxDMV. Verify insurance coverage: the trailer itself needs liability coverage, and the aircraft while on the trailer may need separate inland marine coverage. Some aviation insurance policies cover ground transport incidents; verify with your aviation insurer before purchasing separate coverage. Document trailer modifications for the insurance file. |
| **Flags** | **External: Insurance broker**  **External: TxDMV** |
| **Outputs** | Trailer registration, insurance binder with documented coverage scope, modification disclosure to insurer, aircraft-in-transit coverage confirmation |

## **Phase 5: Integration and Validation**

| 5A | Full Integration Test |
| ----- | :---- |
| **Scope** | Load the real aircraft (with wing attached) onto the trailer using the complete deployment and recovery sequence defined in the Phase 0C CONOPS. Time every step. Identify all interference fits, clearance issues, and operational problems. Iterate on crane controls, wing cradle fit, rotation clearance, wing rail alignment, and tie-down system. Goal: one person, under 45 minutes total, from wing-removal through road-ready (or the reverse). Conduct the sequence at least three times to verify repeatability. Test in wind conditions up to the CONOPS environmental limit. |
| **Flags** | **Depends on All prior phases** |
| **Outputs** | Integration test report with photographs and video, final deployment/recovery procedure (revision of CONOPS), measured time per step, operator training checklist, list of remaining discrepancies and resolution plan |

# **Decision Gates Summary**

The following decisions are unresolved and block downstream work. They are listed in priority order. Resolving the first three unlocks Phase 1 (trailer procurement).

| \# | Decision | Options Under Consideration | Blocks | Notes |
| :---- | :---- | :---- | :---- | :---- |
| **1** | **Wingspan** | 32–38 ft range; coupled to wing loading and flap decision | Trailer length, crane extension, overhang | The single most impactful decision for trailer design |
| **2** | **Flaps or flapless** | Flapless simplifies wing, adds 3–5 ft span | Wingspan (Gate 1), trailer length | Flapless preferred for simplicity; span penalty is absorbed by trailer overhang |
| **3** | **Boom attach or detach** | Stays attached (recommended) vs detachable | Trailer floor layout, tail clearance | Attached eliminates a flight-critical joint and a second handling operation |
| **4** | **V-struts during stow** | Wing stows with struts attached vs struts detach first | Wing channel width, crane operation | Struts attached saves time; struts off gives narrower channel |
| **5** | **Aircraft charging from trailer** | Yes (10–15 kW system) vs No (3 kW system) | Electrical system size, cost, weight | Charging capability makes trailer a complete mobile base |
| **6** | **Shore power standard** | 30A TT-30 vs 50A 14-50 | Inlet hardware, wiring gauge | 50A required if aircraft charging; 30A sufficient for tools only |

# **Crane System Concept**

## **Reference Design**

The crane concept is derived from burial vault delivery trucks, which use a longitudinal overhead beam with a traveling hoist that extends past the rear of the vehicle bed. This proven industrial concept is adapted for aircraft wing handling.

## **Operational Sequence**

The following sequence describes wing removal from the aircraft for transport loading. The reverse sequence is used for deployment.

1. Aircraft taxis forward to the rear of the trailer, oriented nose-to-trailer, and is chocked.

2. Crane beam extends rearward from the trailer roof (telescoping or fixed overhang) to position the trolley/hoist above the wing center of gravity (near the root, at the spar carry-through).

3. Hoist lowers the wing cradle/sling. Operator attaches the cradle to the wing lift fittings.

4. Wing attachment bolts are removed, disconnecting the wing from the fuselage. Electrical, fuel, coolant, and TKS quick-disconnects are separated.

5. Hoist lifts the wing clear of the fuselage. At this point, the wing is suspended from the crane in its flight orientation (perpendicular to the trailer).

6. The wing rotates 90 degrees on the swivel bearing, from perpendicular to parallel with the trailer. This rotation is operator-controlled (not free-swinging). Each wing tip sweeps through a half-circle of radius equal to half the wingspan; adequate clearance from the trailer, fuselage, and any obstacles must be maintained.

7. Trolley retracts forward along the beam, sliding the now-parallel wing into the roof storage channel. Wing rests on padded rails.

8. Wing is secured with tie-downs in the storage channel. Weather cover is closed.

9. Pod+boom is rolled or winched onto the trailer floor and secured.

10. Crane beam is retracted or locked in travel position. Wing tip overhang flagged/lit as required.

## **Key Design Parameters**

| Parameter | Estimated Value | Driver |
| :---- | :---- | :---- |
| Crane overhang past trailer rear | 5–6 ft | Distance from trailer end to wing attach point when aircraft is parked nose-to-trailer |
| Lift load (wing dry weight) | 250–400 lbs | Wing structure \+ 2× Honda generators \+ coolant \+ TKS \+ plumbing. Fuel drained before removal. |
| Beam bending moment | 1,250–2,400 ft·lbs | Overhang × lift load. Sizes beam cross-section. |
| Rotation clearance radius | 16–19 ft | Half wingspan. Area must be clear of obstacles during rotation. |
| Hoist travel (beam length) | 30–36 ft | From overhang position to full-forward stow position. Approximately equals trailer box length. |
| Safety factor | 2.0× static, verified by load test at 1.5× | Standard practice for lifting equipment |

# **Preliminary Risk Register**

| \# | Risk | Likelihood | Impact | Mitigation |
| :---- | :---- | :---- | :---- | :---- |
| **R1** | Height exceeds 14 ft with crane and wing stowed | Medium | High | Verify height budget with actual trailer dimensions before purchasing. Select low-deck trailer if needed. Design crane beam to fold flat for transport. |
| **R2** | Wind gust catches wing during 90-degree rotation | Medium | High | Define CONOPS wind limit for crane operations (suggest 15 kt max). Design controlled rotation mechanism (not free-swinging). Include abort procedure: if gust occurs mid-rotation, lower wing to ground on padded cradle. |
| **R3** | Roof modification compromises trailer torsional rigidity | Medium | Medium | Analyze roof contribution to frame stiffness before cutting. Add compensating structure (longitudinal stiffeners, cross-bracing) as part of Phase 2B design. |
| **R4** | Single-person operation takes too long (\>60 min) | Medium | Low | Prioritize electric hoist over manual. Design all connections for quick-disconnect. Practice sequence with dummy wing. Accept that early operations may be slower; speed comes with practice. |
| **R5** | Wingspan decision changes after trailer purchased | Low | High | Do not purchase trailer until Phase 0A is complete. Size trailer for the upper end of the expected wingspan range to provide margin. |
| **R6** | Trailer weight with modifications exceeds tow vehicle capacity | Low | Medium | Track weight budget through all phases. Prefer aluminum trailer and lightweight crane materials. Verify GCWR before and after modifications. |

# **Immediate Next Actions**

The following actions are needed to begin Phase 0:

11. Resolve the wingspan decision. Run the trade study linking wing loading, stall speed, aspect ratio, and trailer length. The interactive trade tool developed in the design sessions provides the parametric framework; the decision requires fixing the gross weight estimate and choosing the acceptable stall speed for the flapless case.

12. Resolve the flaps/flapless decision. This is tightly coupled to wingspan. Recommendation: go flapless. The simplicity benefit is large, the span penalty is modest (3–5 ft), and the trailer overhang concept absorbs the extra length without requiring a longer trailer.

13. Resolve the boom attachment decision. Recommendation: boom stays permanently attached. This eliminates a flight-critical joint, eliminates a second handling operation during deployment, and the length penalty (pod+boom \~23–25 ft) fits easily within a 28–32 ft trailer.

14. Produce the aircraft 3-view drawing with frozen external dimensions. This drawing is the master reference for all trailer work.

15. Write the CONOPS (Phase 0C). This can be drafted in parallel with the geometry decisions, but must be finalized after dimensions are locked.

16. Begin surveying COTS trailer options and requesting quotes. This can happen informally during Phase 0 to develop cost understanding, but the purchase order waits for Phase 0 completion.

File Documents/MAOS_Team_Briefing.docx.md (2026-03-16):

**MAOS**

MOBILE AVIATION OPERATING SYSTEM

*TEAM BRIEFING  —  PRELIMINARY DESIGN  —  EXPERIMENTAL AMATEUR-BUILT*

March 2026 — FAA EAB • 51% Rule

| THE CORE IDEA This aircraft is designed as a complete mobile aviation operating system. The airplane and its trailer are co-equal components, designed together from first principles. The system requires no fixed infrastructure — no hangar, no FBO, no ground crew. A single pilot can deploy, operate, and recover the complete system from any suitable airstrip. |
| :---- |

# **1\.  What We Are Building**

MAOS is a four-seat, IFR-capable, series-hybrid experimental airplane being designed and built under FAA Experimental Amateur-Built rules (the 51% rule). It is a clean-sheet design that draws on Burt Rutan’s philosophy of inherent aerodynamic safety and Jim Bede’s insistence that a determined amateur should be able to build it in a two-car garage.

The project is currently in preliminary design. No metal has been cut. This is the moment when additional perspective has the most leverage.

| TARGET PERFORMANCE |  |
| :---- | :---- |
| **Configuration** | High-wing, pod-and-boom, tricycle gear, conventional tail |
| **Seats** | 4 — full-width 50-inch cabin |
| **Cruise speed** | 155 KTAS |
| **Range** | 1,000 nm |
| **Endurance** | 7 hours |
| **Service ceiling** | 17,500 – 20,000 ft |
| **Useful load** | 1,200 lbs including fuel |
| **Propulsion** | Series hybrid — twin ICE generators, dual electric rim-drive props |
| **IFR** | Yes — TKS ice protection, full panel |
| **Regulatory** | FAA Experimental Amateur-Built, 51% rule from day one |

# **2\.  The Fuselage — Pod-and-Boom**

The fuselage is a pod-and-boom configuration. The ‘pod’ is a self-contained pressure vessel carrying the crew and all systems. The ‘boom’ is a structural tube connecting the pod to the tail. The two are different structures serving different jobs, and separating them simplifies both.

## **Why a Pod**

A conventional fuselage tapers from a wide mid-section to a narrow tail. That taper wastes cabin space, complicates frame construction, and forces the designer to run systems around structural compromises. A cylindrical pod avoids all of that:

* Constant cross-section — every frame is the same part. Fabrication is repetitive, not unique.

* Pressure vessel geometry — a cylinder is the optimal shape for pressurization loads. No corners, no stress risers.

* 50-inch interior width — comparable to a Cessna 210\. Two adults in the rear do not share a kidney.

* All systems (electrical, avionics, environmental) are accessible from inside the pod during build and maintenance.

* Fire separation built in — the generators are in the wing, not in the same compartment as passengers.

## **Pod Dimensions**

| FUSELAGE POD — DWG MAOS-STR-001 |  |
| :---- | :---- |
| **Exterior width** | 52 inches |
| **Exterior height** | 58 inches |
| **Interior cabin width** | 50 inches |
| **Interior headroom** | 56 inches floor-to-ceiling |
| **Pod length** | 156 inches (13.0 ft) |
| **Frame spacing** | 12-inch typical |
| **Door** | 26 × 48 in, plug-type, inward-release, port side |
| **Pressurization** | Provision built in; activation deferred to v1.1 |
| **Empty pod structure** | \~168 lbs estimated |

## **Why a Boom**

The tail boom is a simple structural tube — extruded aluminum or composite. It carries tail loads back to the pod and, in this design, also carries the propulsion system at its aft end. It is the ideal structure for that job because a tube in bending and torsion is weight-efficient, and a tube in tension (from propulsion thrust) is the most efficient use of a tube that exists.

The boom attaches to the pod at a single bolted flange (Station FS144). Remove eight bolts and the boom separates from the pod — relevant for shipping, storage, and trailer integration.

# **3\.  The Wing — Removable, With the Engines Inside It**

The wing is a one-piece structure that lifts off the fuselage as a single unit. The generators — two small ICE engines running in pure generator mode — are mounted inside the wing center section, flush with the upper skin. When the wing comes off the airplane for trailering, the generators come with it. They remain wired to their respective coolant loops. The wing is a self-contained energy module.

## **Wing Parameters**

| WING — CURRENT DESIGN |  |
| :---- | :---- |
| **Span** | 37.4 ft |
| **Wing area** | 140 ft² |
| **Aspect ratio** | 10.0 |
| **Root chord** | 5.0 ft |
| **Tip chord** | 2.5 ft (tapered) |
| **Airfoil** | Riblett GA35-615 (GA 35-series, 15% thickness) |
| **Primary spar** | 6.0-inch OD, 0.25-inch wall, 6061-T6 aluminum tube |
| **Fuel capacity** | 94 gallons available — 63 gallons required for mission |
| **Struts** | V-strut braced — wire-braced designs are for ultralights |
| **Lift type** | High-wing — inherently self-leveling, better lowspeed stability |
| **Anti-ice** | TKS weeping system, leading edge |

## **Generator Installation in the Wing**

Each generator engine sits in the wing center section between the spars, with its axis running roughly fore-to-aft. This is not a novel concept — it is how the Dornier Seastar and several experimental designs handle overwing powerplants. The advantages for MAOS are substantial:

* No external nacelle — zero nacelle drag. The upper wing surface has a flush NACA inlet and a lower-surface exhaust exit. That is the complete external signature.

* Fire separation — the generators are outboard of the pressure vessel and above the wing, not in the same bay as passengers.

* Structural efficiency — the engine mass hangs at the wing’s strongest point, the spar carry-through, where the structure already exists to handle large loads.

* Accessibility — removable upper wing skin panels allow full generator access for maintenance. No cowl to remove, no special tooling.

* Wing-off servicing — when the wing is on the trailer, both generators are fully accessible at table height. No ladders, no craning your neck into a hot engine bay.

## **The Crane and Trailer Integration**

The trailer is not a passive carrier. It is an active ground support system. The wing does not lift off by hand or by rented crane. It lifts off by a small davit crane that is part of the trailer structure.

The sequence for deployment from the trailer:

1\.  Trailer is positioned alongside the fuselage pod on the airstrip.

2\.  Crane arm deploys from trailer — a simple davit on a mast, no hydraulics.

3\.  Lifting bridle attaches to four hard points at the spar carry-through.

4\.  Wing lifts clear of the trailer deck, swings over the pod.

5\.  Wing saddle locates onto the carry-through fitting on the pod. Four bolts.

6\.  Electrical connectors and coolant quick-disconnects are plugged in.

7\.  Struts pin in. Total elapsed time with one person: approximately 45 minutes.

| THE KEY REQUIREMENT One pilot. One trailer. Any flat strip. No FBO, no hangar lease, no ground crew, no tow vehicle for the airplane. The wing crane is part of the design from the first sketched line — not a retrofit. |
| :---- |

# **4\.  Propulsion — Series Hybrid Architecture**

This is the element of the design that is most unconventional and most worth understanding. The propulsion system is a series hybrid — the same fundamental architecture that has powered diesel-electric locomotives for 80 years and nuclear submarines since the 1950s.

## **How It Works**

The ICE engines never touch the drivetrain. They run in pure generator mode at a single fixed RPM and power setting — maximum efficiency, always. All thrust comes from twin electric rim-drive motors on the tail boom. The generators charge a small battery buffer that covers peak demand and provides emergency reserve.

| POWER FLOW |  |
| :---- | :---- |
| **Energy source** | Twin ICE generator engines — motorcycle-class, \~60 HP each, wing-mounted |
| **Generator output** | \~120 HP combined continuous electrical output |
| **Buffer battery** | 3–5 kWh solid-state — covers takeoff gap and 10-minute emergency reserve |
| **Propulsion** | Dual contra-rotating rim-drive electric motors, tail boom |
| **Motor supplier** | Beyond Motors AXM3 (Slovenia) — 220 kW peak, 27 kg each |
| **Contra-rotation** | Zero net torque. No P-factor. No Vmc. Motors cancel each other. |
| **Folding props** | Prop blades fold aft when unpowered. Glide ratio: \~17:1 from 17,500 ft. |
| **Altitude** | Full electric motor power at any altitude. Generators de-rate gracefully. |
| **Fuel** | Pump gasoline — mogas, same as your car |

## **Why This Matters to a Pilot**

Three things about this architecture that every pilot in this neighborhood should find interesting:

* No Vmc. None. Both motors are on the centerline. Losing one generator reduces thrust symmetrically. There is no asymmetric thrust condition that exists in this airplane at any airspeed. The accident mode that kills people in conventional twins on departure is not available to this airplane.

* Engine failure on takeoff is not an emergency. Generator fails at Vr — battery sustains both motors, both props keep turning, thrust reduces gradually. Pilot has minutes, not seconds. The failure mode goes from violent and immediate to managed and gradual.

* Full power at any altitude. Electric motors are not affected by air density. The generator de-rates with altitude. The battery covers the difference during climb. At 17,500 feet you have the same thrust as at sea level.
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

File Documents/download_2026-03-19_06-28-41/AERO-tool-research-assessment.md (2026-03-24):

# AERO Tool Research Assessment — Aerodynamics Analysis Capability

**Date:** 2026-03-17  
**Agent:** AERO  
**Priority:** Critical path — DG-002, DG-007, DG-010 blocking  
**Budget target:** $0 (free/open source tools only)

---

## Executive Summary

Research completed on 5 aerodynamics tools for MAOS design validation. **Recommendation**: VSPAERO + AVL + Python workflow provides complete capability to resolve all three blocking decision gates within budget constraints.

**Critical finding**: Current wing loading at 17.4 lb/ft² (MTOW 2,430 lbs, 140 ft² wing) is at AERO concern threshold. Tool validation needed immediately.

---

## Decision Gate Requirements vs. Tool Capabilities
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

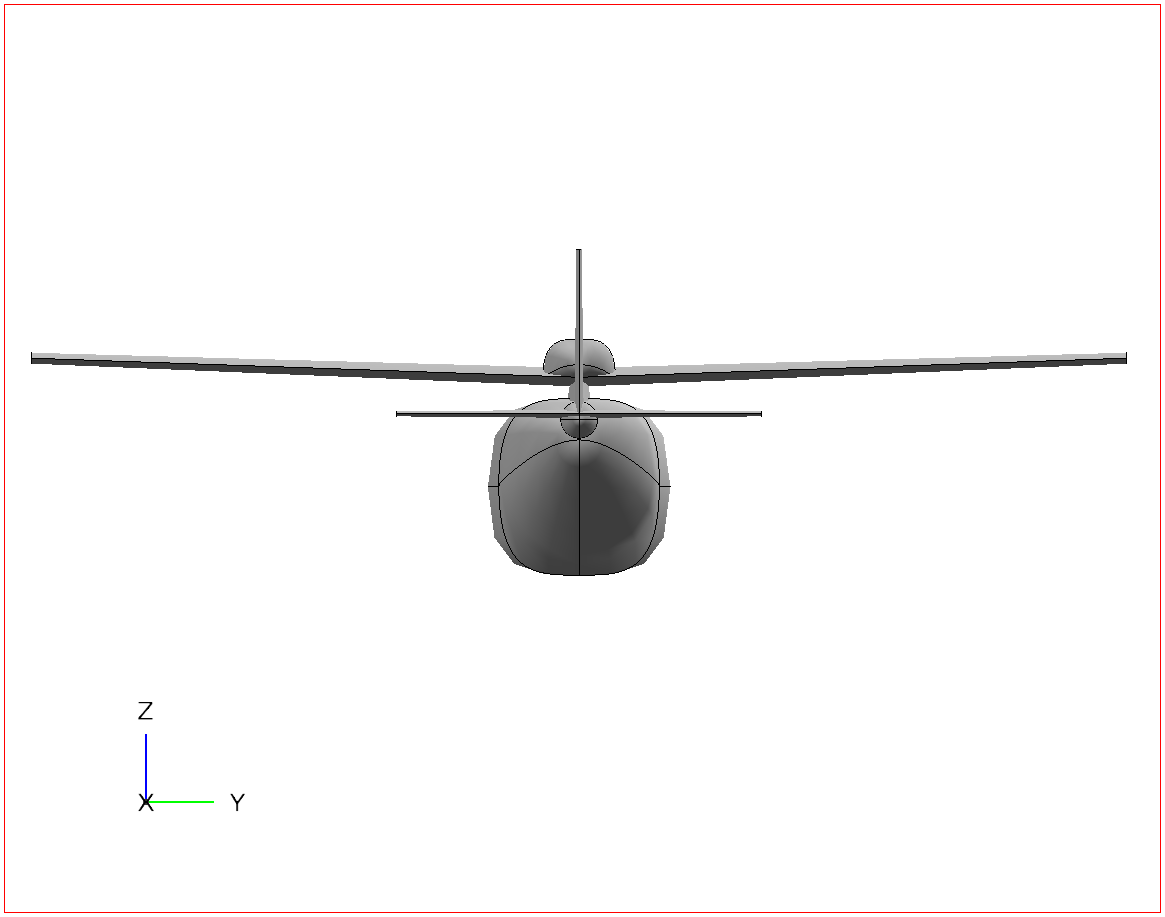
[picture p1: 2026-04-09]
3d_models/maos_pylon_ice_rear.png

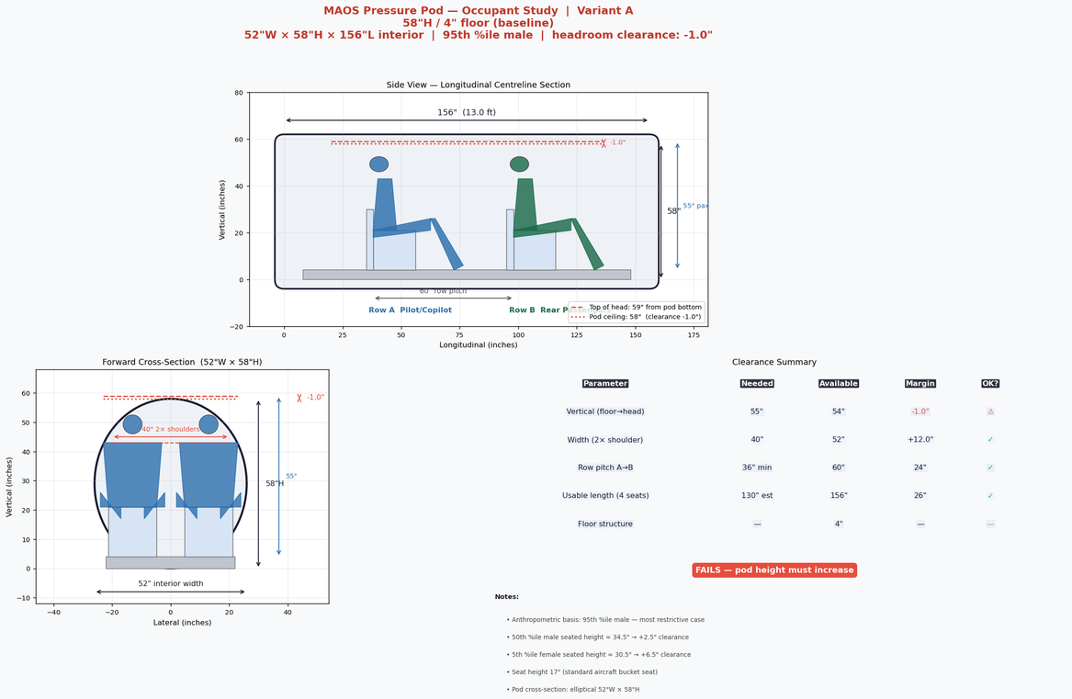
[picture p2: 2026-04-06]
3d_models/dummy/maos_pod_A_small.png

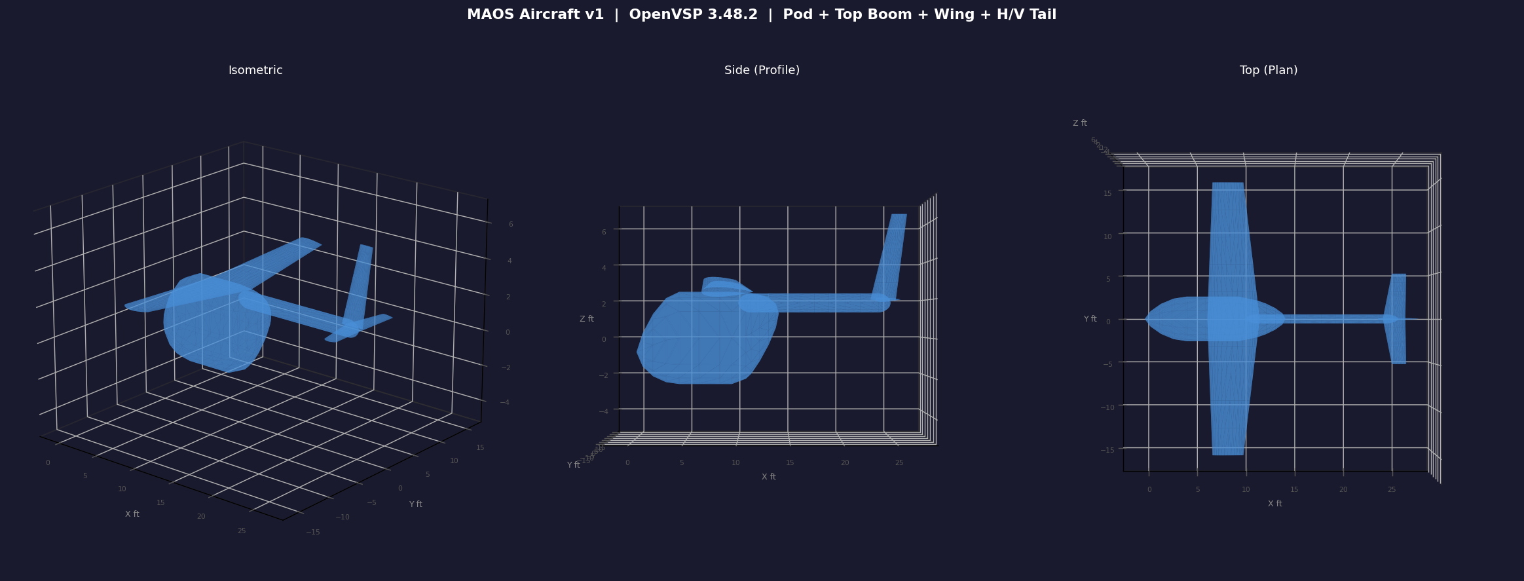
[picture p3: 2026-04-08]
3d_models/maos_aircraft_v1_preview.png

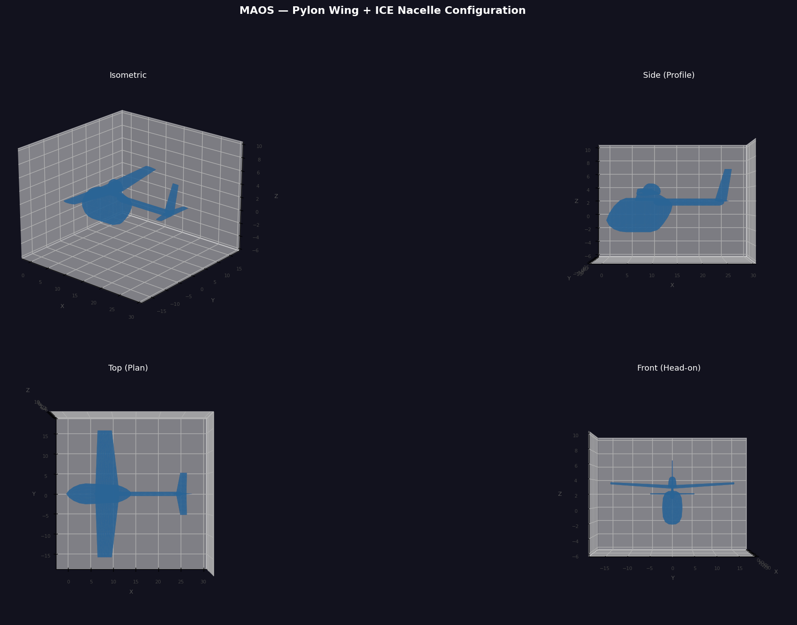
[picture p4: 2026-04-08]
3d_models/maos_pylon_ice_render.png

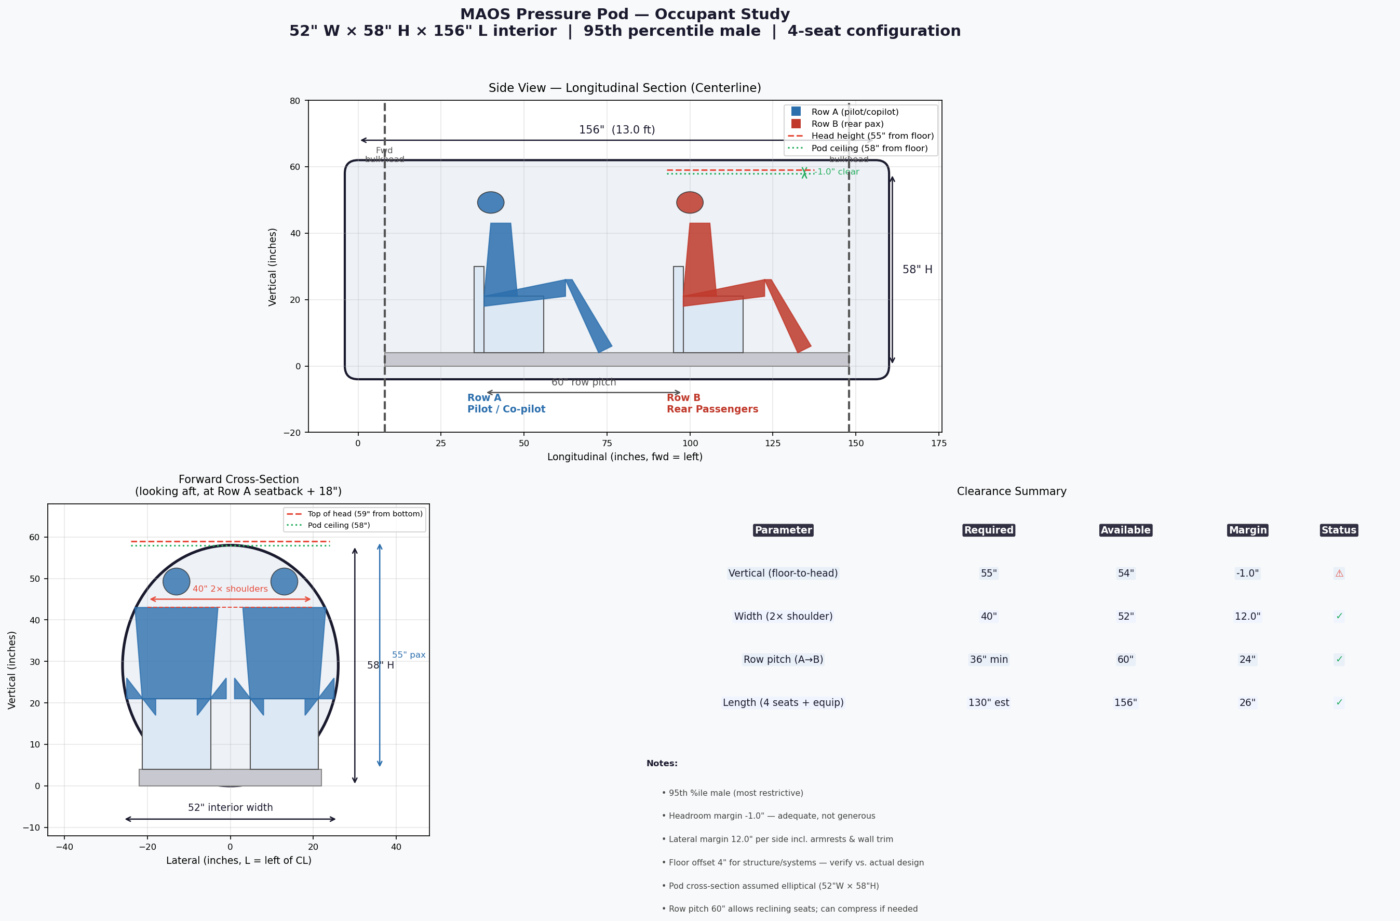
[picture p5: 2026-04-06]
3d_models/dummy/maos_pod_occupant_study.png

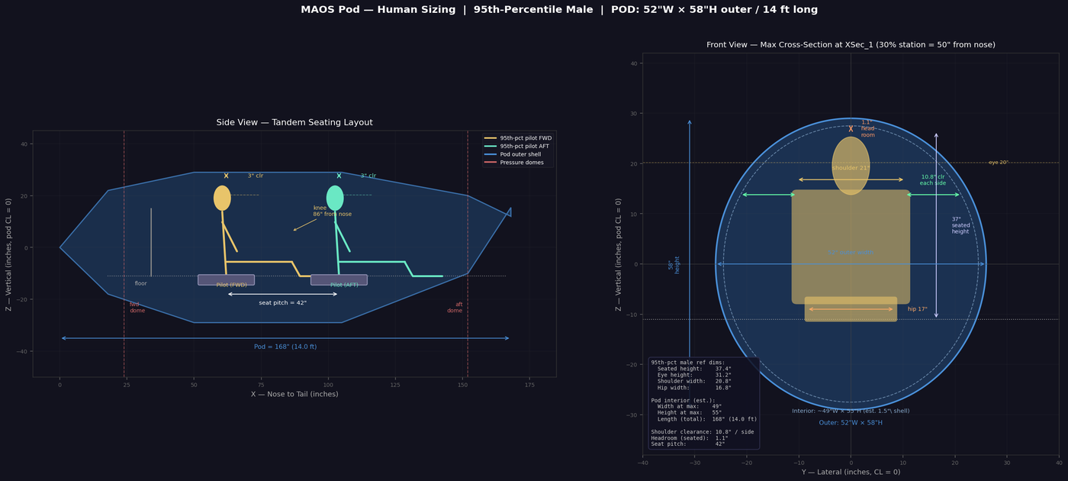
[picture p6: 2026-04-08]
3d_models/maos_pod_human_sizing_small.png

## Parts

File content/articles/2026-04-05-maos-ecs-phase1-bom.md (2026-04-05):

---
title: "MAOS-ECS Phase 1: Environmental Control System BOM"
date: 2026-04-05T14:00:00-06:00
description: "Component-level BOM, sourcing, and bench test plan for the MAOS Environmental Control System — air conditioning, heat, and pressurization."
tags: ["systems", "analysis", "pressurization", "design-decisions", "electric-aviation", "build-in-public"]
author: "AeroCommons Design Board"
summary: "First BOM article for the MAOS-ECS sub-project. Covers the three subsystems — refrigeration/AC, cabin heating, and pressurization — using 400V EV-market hardware where possible. Describes how they integrate and how to bench-test the system before the airframe exists."
project: "maos"
article_type: "analysis"
draft: false
---

## Project: MAOS-ECS

**Project ID:** MAOS-ECS
**System:** Environmental Control System — cabin air conditioning, heating, and pressurization
**Phase:** 1 — Component BOM and bench test architecture
**Date:** 2026-04-05
**Status:** Preliminary

---

## What This System Has to Do

The MAOS cabin is a pressurized composite cylinder approximately 48 inches in diameter. It needs to remain livable from sea level to a pressurized flight altitude of 20,000 ft, in ambient temperatures ranging from -40°F to 100°F on the ground.

Three subsystems in scope:

1. **Refrigeration / Air Conditioning** — remove heat from the cabin, dehumidify incoming air
2. **Cabin Heating** — warm the cabin in cold conditions, particularly at altitude
3. **Pressurization** — maintain cabin altitude at or below 8,000 ft up to 20,000 ft flight altitude (approximately 5 PSI differential)

These are not three separate systems. They share air handling infrastructure, share the 400V DC bus, and benefit from integration with the generator engine cooling circuit. Designing them together from the start is the right approach.

---

## Architecture Overview

```
[Generator Engine Coolant Loop]
        ↓ waste heat
[Cabin Heat Exchanger] ──────────────────────→ [Cabin Air Distribution]
        ↑                                               ↑
[EV Heat Pump Compressor] → [Refrigerant Circuit] ─────┘
        ↑
[400V DC Bus]

[Pressurization Centrifugal Blower]
        ↑
[400V DC Bus]
        ↓
[Cabin] → [Outflow Valve] → [Overboard]
```

**Key architectural decisions:**

**400V-native components throughout.** The MAOS HV bus is 400V DC. Modern EV market heat pump compressors run natively at 300–400V. Using them eliminates a DC-DC conversion stage with its associated weight, efficiency loss, and failure point.

**Engine waste heat as primary cabin heat source.** The two generator engines produce significant waste heat through their liquid cooling circuits. At cruise, this heat is essentially free. A simple coolant-to-air heat exchanger in the cabin supply duct provides heat without drawing from the battery or running the compressor in heat-pump mode. The heat pump supplements or replaces this when engines are at low power.

**Separate pressurization circuit.** Pressurization uses a dedicated centrifugal blower, not the AC compressor. These are different requirements — pressurization needs reliable, continuous, controllable airflow at modest pressure ratios; the refrigeration circuit moves refrigerant, not cabin air. Combining them adds complexity without meaningful benefit at this scale.

**Pod integrity preserved.** The MVS camera system (replacing side windows) has already removed four major penetrations from the pressure vessel. ECS duct penetrations will be minimized to two: a supply inlet and the outflow valve exhaust. All penetrations are circular and use double-lip seals.

---

## Subsystem 1: Refrigeration / Air Conditioning

### How It Works

A standard vapor-compression refrigeration cycle. Refrigerant is compressed (compressor) → condensed overboard (condenser, mounted in airstream) → expanded (expansion valve) → evaporated in the cabin supply duct (evaporator). Condensed water drains overboard.

In heat pump mode, the cycle reverses: the cabin evaporator becomes a condenser and heats incoming air. This supplements waste heat recovery at low engine power or on the ground.

### Component BOM — Refrigeration Circuit

| Component | Part / Source | Est. Cost | Notes |
|---|---|---|---|
| **EV Heat Pump Compressor** | Hanon HSC34 electric scroll compressor (salvage from Hyundai Ioniq 5, Kia EV6, or Hyundai Tucson PHEV) | $150–400 (salvage) / $700–1,000 (new aftermarket) | 400V native, variable speed, brushless, ~3–5 kW input, sealed oil charge — the same unit in millions of EVs. PN varies by donor vehicle. Search: "HV electric AC compressor Ioniq 5" |
| **Condenser** | Microchannel aluminum condenser, 12"×10"×1" (custom or HVAC aftermarket) | $80–200 | Sized for 5,000 BTU/h rejection at 150 KTAS. Mounted in wing-root or belly fairing with ram air. Final dimensions TBD pending CFD of installation location. |
| **Evaporator** | Automotive HVAC evaporator core, ~8"×6"×2.5" | $40–100 | Installed in cabin air supply duct. Standard automotive part — size to duct cross-section. |
| **Electronic Expansion Valve (EEV)** | Fujikoki SEES or Sporlan SEI-0.5 | $60–120 | Electronically controlled for variable superheat. Required for heat pump reversibility. |
| **Reversing Valve (4-way)** | Standard HVAC reversing valve, 1/4" connections | $40–80 | Required only if using heat pump heating mode. Can omit for AC-only Phase 1. |
| **Receiver/Dryer** | Standard inline receiver-dryer, compatible with R-1234yf | $25–50 | |
| **Refrigerant** | HFO-1234yf (native to modern EV compressors) | $80–150 / lb (small qty) | ~1–2 lb charge. 1234yf has GWP of 4 vs. R134a at 1,360. Compressor warranty typically requires 1234yf. |
| **Compressor inverter** | Salvage EV compressor inverter from donor vehicle (or standalone EV compressor driver board) | $100–300 (salvage) | The Hanon compressor requires a 3-phase inverter to run. On many EVs this is a separate module. Some OEM inverters can be PWM-commanded via CAN; others need aftermarket driver. Research required on specific donor vehicle. |
| **High/Low pressure switches** | Saginomiya or Parker dual pressure switch | $30–60 | Safety cutout — prevents compressor operation outside limits. |
| **Refrigerant hose/fittings** | Parker or Gates barrier hose, A/C fittings | $80–150 | Use barrier hose rated for 1234yf. Length TBD pending layout. |
| **Subtotal — Refrigeration** | | **$705–2,110** | |

### Notes on the EV Compressor

This is the pivotal component selection. The Hanon HSC34 and similar units (used in Ioniq 5, EV6, Ioniq 6, various Stellantis EVs) are 400V 3-phase scroll compressors. They are compact (~6 kg), efficient, and produced in enormous volume — which keeps salvage prices low and means replacement parts will be available for decades.

The challenge is the inverter/controller. Some donor vehicles have the inverter ± CAN controller as a separable module; others integrate it tightly with the thermal management ECU. **Before purchasing the compressor, source the inverter from the same donor vehicle.** Then bench-test the pair running on a 400V bench supply before committing to installation.

Alternative: Sanden SD7V EV or Sanden TRSA09 variants designed for OEM EV applications. Slightly higher cost new but more aftermarket controller support exists.

---

## Subsystem 2: Cabin Heating

### Architecture

Primary heat source: **generator engine coolant waste heat** via a liquid-to-air heat exchanger in the cabin supply duct. At cruise power, two 400cc engines produce approximately 10–20 kW of waste heat in their cooling circuits. Even capturing 20% of this for cabin conditioning provides 2–4 kW of heat — more than adequate for cruise heating.

Secondary/ground heat source: **PTC (Positive Temperature Coefficient) resistance heaters** drawing from the 400V bus. Used on the ground before engines are at temperature, and as boost heat.

Tertiary: **Heat pump mode** from the refrigeration circuit above. Useful at low engine power.

### Component BOM — Heating

| Component | Part / Source | Est. Cost | Notes |
|---|---|---|---|
| **Coolant-to-air heat exchanger** | Automotive heater core, ~10"×7"×2" (e.g., Delphi or Valeo unit from any liquid-cooled passenger car) | $30–80 | Installed in cabin supply duct in series with evaporator. Coolant lines from generator engine circuit routed through pod — length TBD pending layout. |
| **Coolant control valve** | Automotive coolant control valve (e.g., Continental Automotive or Hella) or simple manual ball valve for Phase 1 | $30–120 | Modulates heating output. Simple on/off ball valve adequate for bench development. |
| **PTC heater elements (backup)** | 2× 1.5 kW HV PTC heater elements, 400V nominal (EV/PHEV aftermarket) | $60–150 each | Used in EV cabin heaters — sources: Alibaba industrial suppliers, EV parts suppliers. Specify 300–450V operating range. |
| **PTC controller** | PWM relay or solid-state relay for PTC elements | $20–60 | Simple on/off or staged control for bench Phase 1. PID controller in Phase 2. |
| **Subtotal — Heating** | | **$200–590** | |

---

## Subsystem 3: Pressurization

### Architecture

A dedicated oil-free centrifugal blower draws outside air, compresses it to cabin pressure, and delivers it to the cabin supply duct. Cabin pressure is controlled by a motorized outflow valve exhausting to atmosphere. A differential pressure sensor provides feedback to a cabin pressure controller, which commands the outflow valve.

This is not a bleed-air system. There is no equivalent to a turbocharger bleed tap on motorcycle-derived generator engines running as pure generator drives. This must be an independent electric compressor.

The target: maintain 5 PSI differential (≈8,000 ft cabin at 20,000 ft flight altitude), with maximum outflow rate sufficient to handle door seal leakage and occupant CO₂ scrubbing. Mass flow requirement is modest — approximately 20–40 CFM continuous.

### Component BOM — Pressurization

| Component | Part / Source | Est. Cost | Notes |
|---|---|---|---|
| **Centrifugal cabin air compressor** | Domel 799.3.xxx series centrifugal blower (brushless DC, oil-free, used in CPAP/medical equipment and industrial applications) — or Ametek Rotron centrifugal blower | $200–800 | These are oil-free centrifugal blowers capable of modest pressure ratios (1.2–1.5:1) at 20–50 CFM. Adequate for pressurization at the cabin volumes involved. Need to bench-verify pressure rise at altitude (lower inlet density). **This is the component requiring most development work.** A proper aviation-grade turbocompressor (Barber-Nichols: $15–30k) is the end-state; a development-grade centrifugal is appropriate for Phase 1 bench work. |
| **Compressor motor controller** | VESC 75/300 (open-source BLDC controller, 300V max) or Kelly KLS-H series (72–120V variants) | $150–400 | For bench development. Final aircraft controller will be sized to the production compressor selection. VESC is configurable and well-documented. |
| **Outflow valve** | Used Piper PA-28/32/34 outflow valve (aircraft salvage) — or fabricate: 2" aluminum butterfly valve + Actuonix linear actuator | $150–500 (used OEM) / $80–200 (fabricated) | Used Piper outflow valves are available through aircraft salvage (Aviall, salvage yards). Fabricated valve adequate for bench. |
| **Outflow valve actuator** | Included in OEM valve, or Actuonix L16 linear actuator for fabricated valve | $40–80 | Proportional control — not on/off. |
| **Cabin differential pressure sensor** | Honeywell PX2 series (0–15 PSI differential) or Sensata 1865 series | $80–200 | Two sensors recommended — primary and backup. Differential reading: cabin – ambient. |
| **Cabin altitude indicator** | United Instruments 3000 cabin altimeter (used aircraft market) | $80–200 | Backup visual display for crew. |
| **Cabin pressure controller** | Custom: Arduino Mega or STM32 + LCD + PID control loop (Phase 1 bench dev) | $50–150 | Purpose-built controller for Phase 1. Software controls outflow valve position to maintain target cabin altitude. ACE Thermal eKAPS (~$3,000) is the production target; custom controller is the bench development tool. |
| **Safety relief valve — positive** | Clippard URV-3 or Parker inline relief valve, set at 5.5 PSI differential | $40–100 | Hard limit — prevents overpressurization regardless of controller state. |
| **Safety relief valve — negative** | Same or equivalent, reverse-mounted, set at -0.5 PSI (prevents vacuum if outflow valve sticks open at altitude) | $40–100 | |
| **Inlet filter/silencer** | Automotive intake filter (K&N or equivalent) + flexible silencer boot | $30–60 | RAM air inlet TBD pending fuselage location. |
| **Subtotal — Pressurization** | | **$960–2,790** | |

---

## Shared Air Handling

| Component | Part / Source | Est. Cost | Notes |
|---|---|---|---|
| **Cabin supply duct** | 4" diameter spiral aluminum duct (HVAC supply) + custom transitions | $40–100 | Evaporator → heater core → distribution outlets. Insulated where cold exterior surfaces are adjacent. |
| **Distribution outlets** | 4× Automotive-style adjustable vents (dash-mount style) | $20–60 | Positioned per cabin layout. |
| **Cabin recirculation fan** | 12V or 24V brushless blower fan (automotive HVAC blower motor) with DC-DC converter from 400V bus | $30–80 | Provides cabin air circulation independent of fresh-air pressurization flow. |
| **Condensate drain** | Simple gravity drain with check valve, routed overboard | $15–30 | Prevents cabin water accumulation from evaporator. |
| **Subtotal — Air Handling** | | **$105–270** | |

---

## Total System BOM Summary

| Subsystem | Low Est. | High Est. |
|---|---|---|
| Refrigeration / AC | $705 | $2,110 |
| Heating | $200 | $590 |
| Pressurization | $960 | $2,790 |
| Shared Air Handling | $105 | $270 |
| **Total** | **$1,970** | **$5,760** |

The wide range reflects the salvage vs. new spread on the compressor and outflow valve, and the development vs. production choice on the pressure controller. A realistic Phase 1 bench build using primarily salvage EV components and a custom pressure controller lands around **$2,500–3,500**.

---

## How It Connects — Integration Notes

**400V bus to compressor:** The EV compressor inverter runs directly from the HV bus. Add a dedicated 20A HV fuse and contactor. Total compressor draw at full load: ~12A at 400V.

**Coolant loop to heater core:** Tee off the generator engine coolant circuit. A proportional coolant valve controls heat delivery to the cabin. Coolant temperature at cruise: ~80–90°C — more than adequate for cabin heating. This circuit is entirely passive when the valve is closed.

**Pressurization compressor to cabin:** Clean filtered air from the blower enters the supply duct upstream of the evaporator and heater core. Processed (conditioned) air exits at cabin distribution outlets. The outflow valve exhausts through the pod skin to atmosphere — this is the only overboard penetration needed for the pressurization circuit.

**Sensors and controller:** The cabin pressure controller reads differential pressure (cabin vs. ambient) and cabin altitude. It commands the outflow valve actuator over a 0–5V or PWM signal. Safety relief valves are purely mechanical — no electrical path, no failure mode.

---

## Bench Test Plan — Phase 1

The value of designing systems first is that you can build and test the ECS before the airframe exists. The bench test proves the components work, characterizes performance, and surfaces problems early.

### Test Article

Build a pressure test box: a plywood-and-fiberglass box approximately 8 cubic feet (representing a scaled section of the cabin volume, sized to fit in a workshop). Seal it with foam weatherstripping. Install two circular penetrations — supply inlet and outflow valve mount.

This is not a fatigue specimen. It is a functional systems test fixture for characterizing flow, pressure, and thermal performance at 5 PSI differential (which the box must survive).

### Test Sequence

**Phase 1A — Pressurization circuit only**

1. Install centrifugal compressor, outflow valve, pressure sensors, and pressure controller on test box
2. Apply 120V AC power to compressor (bench supply, not HV bus yet)
3. Characterize: What flow rate and power draw is needed to maintain 5 PSI differential against simulated leakage (deliberate small orifice)?
4. Tune PID controller — target: stable cabin altitude within ±200 ft, no hunting
5. Test safety relief valves: verify set points

**Phase 1B — Refrigeration circuit**

1. Build refrigeration circuit on bench (not in box yet): compressor, condenser (shop fan for airflow), expansion valve, evaporator
2. Charge with 1234yf, verify for leaks
3. Run compressor on bench HV supply — verify cooling performance, measure COP
4. Heat pump mode if reversing valve installed: verify heating output

**Phase 1C — Integrated**

1. Install evaporator and heater core in supply duct of test box
2. Run pressurization + refrigeration simultaneously
3. Measure: cabin temperature, humidity, pressure, power draw from HV bus
4. Simulate flight profile: ambient temperature change, altitude change (bleed pressurization system to simulate climb/descent)

### Instrumentation Required for Bench Testing

| Instrument | Purpose | Cost |
|---|---|---|
| Differential pressure gauge (0–10 PSI) | Verify actual ΔP across test box | $40–100 |
| Thermocouple + DAQ (4-channel) | Supply air temp, cabin temp, heater core in/out | $80–200 |
| Clamp-type power meter (for HV circuit) | Measure compressor power draw | $50–150 |
| Refrigerant manifold gauges (1234yf compatible) | Refrigerant circuit pressures | $80–200 |
| Anemometer | Supply duct airflow velocity | $30–80 |

---

## What Comes Next (Phase 2)

Phase 1 delivers: working bench proof-of-concept, characterized component performance, validated control logic, verified BOM.

Phase 2 will specify:
- Production compressor (Barber-Nichols or validated production alternative based on Phase 1 flow data)
- Aircraft-grade pressure controller (eKAPS or equivalent)
- Aircraft-grade outflow valve (OEM aviation or engineered custom)
- Final duct routing and cabin integration geometry
- Weight-optimized installation design
- HV harness design for aircraft installation

---

## Related Articles

- [Pressurized Homebuilt Aircraft: A Technical Guide](/articles/2026-03-27-homebuilt-pressurization-guide/) — pressure vessel design, structural requirements
- [Pressurized Homebuilt Case Studies: Lancair IV-P and Veloce 600](/articles/2026-03-27-lancair-veloce-pressurization-case-studies/) — lessons from the field
- [MVS Phase 1: Building a Camera-Only Cockpit for Under $5,000](/articles/2026-04-03-mvs-phase1-component-list/) — window elimination supporting pressurization design

---

*MAOS-ECS Phase 1 — preliminary design*
*All component costs are 2026 estimates based on current salvage and aftermarket pricing. Vendor quotes required before procurement.*
*AeroCommons / MAOS Project — Fort Worth, Texas*

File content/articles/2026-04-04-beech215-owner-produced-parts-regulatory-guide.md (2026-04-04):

---
title: "Owner-Produced Parts for the Beech 215 Prop Governor — FAA Regulatory Guide"
date: 2026-04-04T11:00:00-06:00
description: "Complete regulatory guidance for installing an owner-produced replacement for the Airborne Electronics 350A prop governor under 14 CFR Part 21.303."
tags: ["regulatory", "owner-produced-parts", "faa", "form-337", "avionics"]
author: "Bill Mallard"
summary: "Detailed walkthrough of the FAA owner-produced parts framework for the digital prop governor project — including Part 21.303 compliance, Form 337 requirements, suggested language, data package preparation, and common FSDO questions."
project: "beech215"
article_type: "methodology"
draft: false
---

## Important Disclaimer

This document provides general guidance based on publicly available FAA regulations and policy. **It is not legal advice.** Aviation regulations are complex and subject to interpretation. Consult with your IA and FSDO before proceeding. The regulatory path described here is the most direct and well-supported approach, but your specific situation may vary.

---

## The Regulatory Framework

### What Is an Owner-Produced Part?

**14 CFR Part 21.303(b)(2)** allows an aircraft owner to produce a replacement part for their own aircraft without holding a Parts Manufacturer Approval (PMA), provided:

1. The part is produced by the aircraft owner for installation on their own aircraft
2. The part is produced using the original manufacturer's design data (drawings, specs) or acceptable equivalent data
3. The part is airworthy when installed

**FAA Order 8110.42C** provides additional guidance. The key language: 

> "An owner-produced part may be used to maintain an aircraft without PMA if produced by the owner or operator for installation on aircraft they own or operate."

### How This Project Fits

The Airborne Electronics 350A is:

- **Out of production** (company closed 2010)
- Covered by **STC SA2700WE**
- A **"line replaceable unit"** — the entire governor box is replaced as a unit
- **Fully documented** in the original manufacturer's documentation (which is preserved in this repository)

The new controller:

- Maintains **identical external interface** (7-pin Cannon connector, identical pin assignments, identical signal behaviors on all 7 pins)
- Uses the **same airframe wiring, relays, prop motor, and limit switches**
- Performs the **same defined function**: maintain selected RPM by commanding prop pitch
- Is **produced by the aircraft owner** for installation on their own aircraft

The original manufacturer explicitly designed this unit to be owner-serviced and documented the internal circuit at component level. The service notes state:

> "Do not worry about warranty. It will be honored even though the cover has been removed."

---

## The Path to Legal Installation

### Step 1: Find an IA

You need an **Airframe & Powerplant mechanic holding an Inspection Authorization**. Not every IA is comfortable with avionics or with unusual 337 work. Look for:

- IAs who have worked with Bonanzas specifically
- IAs with avionics background (A&P/IA who also holds a Repairman certificate)
- Contact the **American Bonanza Society (ABS)** — their maintenance clinics and member network are the best resource for finding Bonanza-experienced IAs

### Step 2: FAA Form 337

A **Form 337 (Major Repair and Alteration)** is required because:

- Replacing an STC'd avionics component with a non-PMA part is a **major alteration**
- Automatic propeller control systems are in the **major alteration category**

The 337 needs to document:

- The aircraft (make, model, serial number, registration)
- The work performed (description of the alteration)
- The data used to show airworthiness
- The IA's certification that the work was done in accordance with that data

### Step 3: The Data Package

The **"data used to show airworthiness"** is the critical part. Your data package should include:

1. **Original 350A documentation** — the complete installation instructions and service notes (in this repository under `docs/original_350A/`). This is the baseline definition of the system.

2. **This project's engineering documentation** — specifically the spec document showing:
   - Identical external interface
   - Added safety features (watchdog, mag timeout, relay timeout)
   - Identical output behaviors (relay coil drive current, signal levels)

3. **Pin-for-pin comparison table** — see [WIRING.md](https://github.com/billmallard/Beech215PropController/blob/main/docs/WIRING.md), the "Pinout Cross-Reference" section. Print this for your 337 package.

4. **Ground test results** — completed bench test checklist and ground test results

5. **Your IA's assessment** — that the installed system performs its intended function

### Suggested 337 Description Language

Your IA will write the actual 337, but this is suggested language for the **"Description of Work"** block:

> "Replaced Airborne Electronics Model 350A Solid-State Propeller Governor (per STC SA2700WE) with owner-produced equivalent unit. Replacement unit uses identical 7-pin cannon connector interface, identical pin assignments (Pins A through H), identical relay coil drive outputs on Pins C and D, identical magneto P-lead input configuration on Pin H (10kΩ isolating resistor preserved), and identical panel potentiometer interface on Pins E and F. All airframe wiring, propeller control relays, propeller pitch change motor, and limit switches are unchanged. Replacement controller provides proportional RPM control with hardware watchdog protection, magneto signal loss detection, and motor run-time limiting. System verified per functional test procedure equivalent to Airborne Electronics 350A Installation Instructions Ground Test and Flight Test procedures."

---

## Frequently Asked Questions

### Does this void the STC?

The STC covers the installation of the electric prop control system on the aircraft. Replacing the electronic governor box with an equivalent unit is analogous to replacing any other component with an owner-produced part. **The STC doesn't cease to exist** — the aircraft is still modified per STC SA2700WE. The specific governor unit has been replaced under owner-produced parts authority.

### Can I sell this to other Bonanza owners?

**As a private builder, no** — owner-produced parts authority is specific to your aircraft. If you want to supply this to other owners, you would need either a PMA (expensive, lengthy) or to work with each owner/IA team on a per-aircraft 337.

The practical path for the community is for each owner to order their own PCBs (5 boards for $2 at JLCPCB), build their own unit, and work with their own IA. This repository gives them everything they need to do exactly that.

### What if my FSDO doesn't agree?

FSDO offices vary in their familiarity with owner-produced parts in the avionics context. Some general-aviation FSDOs rarely see this type of work. If you encounter resistance:

- Reference **FAA Order 8110.42C** directly
- Reference **AC 43.13-1B** (Acceptable Methods for Aircraft Inspection and Repair)
- Contact the **American Bonanza Society** — they have experience navigating Bonanza-specific regulatory questions
- Consider requesting a **legal interpretation** from your FSDO in writing before proceeding

### My IA is nervous about this. What should I tell them?

The key points for your IA:

1. The **external interface is byte-for-byte identical** — no airframe changes at all
2. The original manufacturer is **out of business** and the part is genuinely unavailable new
3. The original manufacturer **documented the design at component level** and explicitly expected owners to service it
4. The added safety features (watchdog, mag timeout) **make the replacement safer** than the original, not less safe
5. The bench test procedure is comprehensive and documents that the unit performs its intended function before installation

---

## Additional References

- [14 CFR Part 21.303](https://www.ecfr.gov/current/title-14/chapter-I/subchapter-C/part-21/subpart-D/section-21.303) — Production Approval and Related Requirements (PMA)
- [14 CFR Part 21.303(b)(2)](https://www.ecfr.gov/current/title-14/chapter-I/subchapter-C/part-21/subpart-D/section-21.303) — Owner-produced parts provision
- **FAA Order 8110.42C** — Parts Manufacturer Approval (PMA) Procedures
- **AC 43.13-1B** — Acceptable Methods, Techniques, and Practices — Aircraft Inspection and Repair
- **FAA Form 337** — Major Repair and Alteration form
- **STC SA2700WE** — Airborne Electronics Model 350A original STC
- [American Bonanza Society](https://bonanza.org) — technical resources and IA referrals

---

## Repository Resources

- **Main Documentation:** [Beech215PropController Repository](https://github.com/billmallard/Beech215PropController)
- **Wiring Reference:** [WIRING.md](https://github.com/billmallard/Beech215PropController/blob/main/docs/WIRING.md)
- **Assembly Guide:** [ASSEMBLY.md](https://github.com/billmallard/Beech215PropController/blob/main/docs/ASSEMBLY.md)
- **Bench Test Procedure:** [BENCH_TEST.md](https://github.com/billmallard/Beech215PropController/blob/main/docs/BENCH_TEST.md)

---

**Last Reviewed:** This document was last reviewed for regulatory accuracy in early 2026. FAA regulations and interpretive guidance change over time. Always verify current regulatory requirements before proceeding.

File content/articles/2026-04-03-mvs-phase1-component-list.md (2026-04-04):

---
title: "MVS Phase 1: Building a Camera‑Only Cockpit for Under $5,000"
date: 2026-04-03T16:00:00-06:00
description: "Component list and cost summary for the MAOS Vision System (MVS) – a camera/display system to replace side windows in experimental aircraft."
tags: ["systems", "analysis", "design-decisions"]
author: "CHAIRMAN, MAOS Design Board"
session: "MVS-001"
project: "maos"
article_type: "build-log"
draft: false
---

# MVS (MAOS Vision System) – Phase 1: Component List & Cost Summary
**Date:** 2026-04-03  
**Author:** CHAIRMAN  
**Project:** MAOS Vision System – side‑window replacement by camera/display  
**Phase:** 1 – Executive Summary & Shopping List  
**Next Phase:** Technical Architecture & Integration Details

---

## Executive Summary

The **MAOS Vision System (MVS)** replaces conventional side windows with a hybrid camera/display approach:
- **Windshield retained** for forward direct‑view
- **Three (3) or four (4) HD‑SDI cameras** mounted externally (left, right, aft, optionally forward)
- **Two (2) rugged sunlight‑readable displays** inside the cockpit, fed by a quad multiplexer
- **No‑latency live view** via direct loop‑through or minimal‑delay processing
- **Budget target:** $5,000 (excluding displays, which may exceed this cap)

**Why this approach:**
1. **Structural benefit:** Eliminates side‑window cutouts, simplifying pressurization and improving pressure‑vessel integrity
2. **Weight neutral/saving:** Cameras + wiring ≈ weight of traditional window frames + glass
3. **Operational flexibility:** Can switch between individual camera views, quad‑split, or picture‑in‑picture
4. **First‑of‑its‑kind for EAB:** Demonstrates a path toward fully synthetic vision cockpits

**Key constraints:**
- **Budget:** $5,000 for cameras, multiplexer, wiring, power (displays separate)
- **Redundancy:** Minimum 3 cameras (left, right, aft); forward camera still recommended
- **Timeline:** Months (component spec, purchase, wiring harness fabrication, software if needed)
- **Regulatory:** EAB – no FAA certification required, but must be safe and reliable as primary vision system

This Phase 1 document lists the recommended components, approximate costs, and a high‑level architecture. Phase 2 will detail integration, failure modes, testing, and full project timeline.

---

## Component List & Estimated Costs

| Component | Model / Description | Qty | Unit Price | Line Total | Vendor / Source | Notes |
|---|---|-----|---|---|---|---|
| **HD‑SDI Cameras** | BW‑CAM‑HDNANO (or equivalent) | 4 | $450 | $1,800 | Datatoyz / Badwolf Tech | 1080p, IP67, aviation‑rated bullet cam, 19×56 mm, wide‑angle lens |
| **Quad HDMI Multiplexer** | OREI HD‑401MR (or gofanco QuadView) | 1 | $300 | $300 | OREI / Amazon | 4× HDMI in, 1× HDMI out, 5 display modes, 1080p60, low latency (~32 ms) |
| **HD‑SDI to HDMI Converters** | Blackmagic Design Micro Converter SDI to HDMI | 4 | $80 | $320 | B&H / Amazon | Converts camera HD‑SDI to HDMI for multiplexer input |
| **Power Supply (28 V → 12 V)** | Mean Well SD‑100C‑12 (100 W, 12 V) | 2 | $40 | $80 | Mouser / Digi‑Key | Aircraft 28 VDC → 12 VDC for cameras & multiplexer |
| **Wiring & Connectors** | MIL‑DTL‑38999 series III (or equivalent) | 1 kit | $250 | $250 | Mouser / Aircraft Spruce | Connectors, backshells, pins, wire (shielded, 22 AWG) |
| **Mounting Hardware** | Aluminum brackets, vibration isolators | 1 kit | $150 | $150 | McMaster‑Carr | Custom camera mounts, display panel brackets |
| **Cabling (HD‑SDI)** | Belden 1694A (or equivalent), 25 ft each | 4 | $50 | $200 | Belden distributor | Low‑loss 75 Ω coax for HD‑SDI runs |
| **Cabling (HDMI)** | High‑flex HDMI 2.0, 10 ft | 2 | $30 | $60 | Amazon | From multiplexer to displays |
| **Fuses & Circuit Protection** | Automotive blade fuses, holders | 1 kit | $40 | $40 | Auto parts store | Over‑current protection per camera & display feed |
| **Spares / Contingency** | Extra connectors, cables, misc. | 1 | $300 | $300 | — | 10 % buffer for unforeseen parts / mistakes |
| | | | **Subtotal** | **$3,500** | | **Under $5K budget** |
| **Displays (Not in $5K budget)** | GK‑FA1019 (10.1″, 1500 nits, IP65) | 2 | $600 | $1,200 | Geekland / industrial suppliers | Sunlight‑readable, 9‑36 V DC, capacitive touch, HDMI |
| | | | **Total with Displays** | **$4,700** | | Entire system under $5K if displays included |

**Budget Status:** **$3,500** for core components (cameras, multiplexer, wiring, power) – **$1,500 under** the $5,000 target.  
**Total with Displays:** **$4,700** – still under $5,000 if displays are counted.

---

## High‑Level Architecture

```
External Cameras (4) → HD‑SDI (75 Ω coax) → SDI‑to‑HDMI Converters (4) → HDMI cables → Quad Multiplexer → HDMI output → Displays (2)
                                                     ↓
                                              28 V Aircraft Bus → 12 V DC Power Supplies
```

**Camera placement:**
1. **Left camera** – mounted on left fuselage, forward of wing, looking aft/sideways
2. **Right camera** – mirror of left
3. **Aft camera** – mounted on tail boom or vertical stabilizer, looking forward/down for ground maneuvering
4. **Forward camera** – optional, mounted on nose or windshield frame, provides redundancy to direct windshield view

**Display placement:**
- **Primary display** – pilot’s side, positioned where a traditional side window would be
- **Secondary display** – copilot’s side, same position
- Both displays can show:
  - **Quad‑split** (all four cameras)
  - **Single camera** full‑screen (selectable)
  - **Picture‑in‑picture** (one large, one small)

**Power:**
- Cameras: 12 VDC (typical)
- Multiplexer: 5 VDC via adapter, fed from 12 V supply
- Displays: 9‑36 VDC direct from aircraft 28 V bus (or via DC‑DC converter)

---

## Key Technical Risks & Mitigations (Phase 1 View)

| Risk | Mitigation |
|---|---|
| **Latency** (delay between real world and display) | Use direct loop‑through mode on multiplexer; avoid frame buffers; target <50 ms end‑to‑end |
| **Vibration / EMI** (consumer parts in aircraft environment) | Select industrial‑grade components; use vibration‑isolating mounts; shield all cables |
| **Single‑point failure** (multiplexer dies, lose all cameras) | Design for bypass: ability to connect one camera directly to one display if multiplexer fails |
| **Display failure** (one display goes dark) | Second display remains; can switch views between displays |
| **Camera failure** (one camera dies) | Four‑camera system provides redundancy; remaining three still cover critical arcs |

---

## Next Steps (Phased Approach)

**Phase 1 (Complete)** – Component list & cost summary (this document)  
**Phase 2** – Detailed technical architecture, wiring diagrams, mounting drawings, failure‑mode analysis  
**Phase 3** – Integration plan, software/firmware requirements (if any), testing/validation procedure  
**Phase 4** – Procurement, build, ground testing, flight testing  

**Immediate action items:**
1. **Review this component list** – adjust models/quantities as needed
2. **Begin sourcing quotes** for cameras, multiplexer, displays
3. **Sketch mounting locations** on MAOS pod & boom
4. **Draft Phase 2** – technical architecture (wiring, power, mechanical integration)

---

## Article‑Ready Excerpt

*“Building a camera‑only cockpit for under $5,000 is possible today with off‑the‑shelf industrial components. The MAOS Vision System (MVS) uses four HD‑SDI bullet cameras, a quad HDMI multiplexer, and sunlight‑readable displays to replace side windows entirely—improving structural integrity while providing redundant, selectable views. Total hardware cost: $3,500 for the core system, $4,700 including displays. This Phase 1 shopping list shows exactly what to buy and where to get it.”*

---

**End of Phase 1**  
*Prepared by CHAIRMAN, MAOS Design Board*  
*Next: Phase 2 – Technical Architecture & Integration Details*

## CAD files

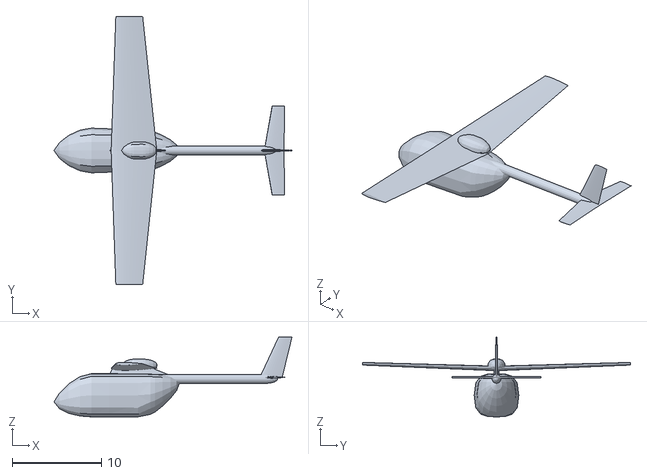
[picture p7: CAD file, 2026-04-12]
3d_models/maos_aircraft_ICE_bump_pylon.obj
26.6 x 30.0 x 8.92

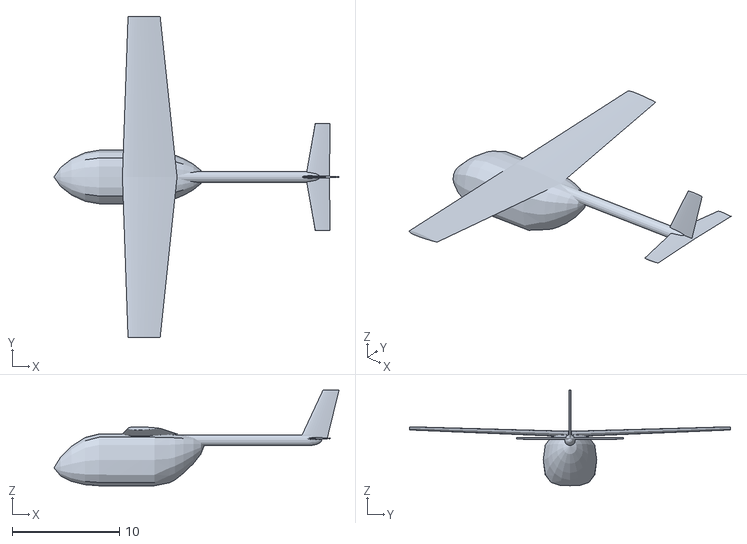
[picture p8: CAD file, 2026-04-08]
3d_models/maos_aircraft_v1.stl
26.6 x 30.0 x 8.92

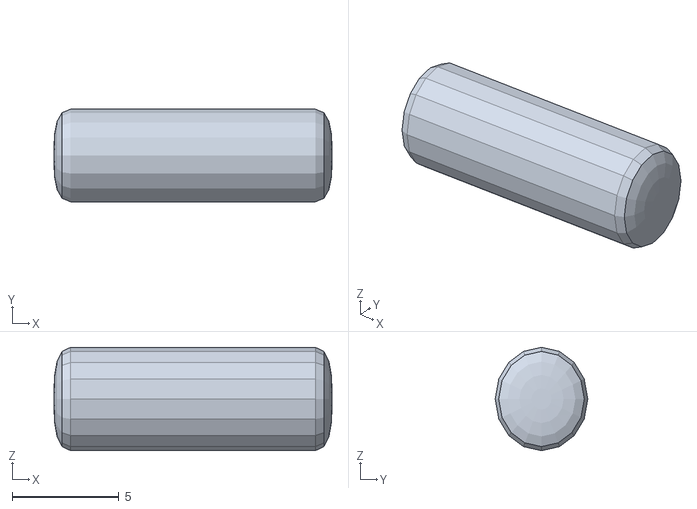
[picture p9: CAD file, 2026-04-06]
3d_models/maos_pod.stl
13.0 x 4.33 x 4.83

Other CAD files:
3d_models/maos_aircraft_v1_ICE_BUMP_Pylon_hires.stl
3d_models/maos_aircraft_v1_ICE_BUMP_Pylon.stl
3d_models/maos_pod.obj

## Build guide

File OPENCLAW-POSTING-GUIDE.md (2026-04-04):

# OPENCLAW — Article Posting Guide

This document tells the openclaw agent exactly how to post a board meeting note or design update as a website article.

---

## What happens when you post

1. You create a markdown file in `content/articles/`
2. You push it to the GitHub repository
3. Cloudflare Pages detects the push and runs `hugo --minify`
4. The article appears live on aerocommons.org/articles/ within ~60 seconds

No human intervention required. No approval step. Push the file, the site rebuilds.

**Note:** AeroCommons transformed to a multi-project hub in v2. All articles now require `project` and `article_type` fields in addition to tags. MAOS-specific content is at `/projects/maos/` while the homepage showcases all projects.

---

## File naming convention

```
content/articles/YYYY-MM-DD-short-title.md
```

Examples:
```
content/articles/2026-03-16-board-session-001.md
content/articles/2026-04-02-wingspan-decision.md
content/articles/2026-04-15-propulsion-motor-selection.md
```

**Rules:**
- Date first, always, in `YYYY-MM-DD` format
- Lowercase, hyphens only — no spaces, no underscores, no special characters
- Keep the slug short but descriptive
- One file = one article

---

## Required front matter

Every article must begin with this YAML block between `---` markers:

```yaml
---
title: "Your Article Title Here"
date: 2026-03-16T09:00:00-06:00
description: "One sentence. Shown in article cards and meta tags. Make it specific."
tags: ["board-meeting", "propulsion"]
author: "AeroCommons Design Board"
summary: "Two-sentence summary for article cards. More detailed than description."
project: "maos"
article_type: "design"
session: "BOARD-001"
draft: false
---
```

### Field reference

| Field | Required | Notes |
|---|---|---|
| `title` | Yes | Full human-readable title. Use quotes. |
| `date` | Yes | ISO 8601 with timezone. Use `-06:00` for US Central. |
| `description` | Yes | One sentence. This appears in meta tags and article cards. |
| `tags` | Yes | Array of lowercase tags. See tag list below. |
| `author` | Yes | Who/what produced this. Use `"AeroCommons Design Board"` for board sessions. |
| `summary` | Recommended | Two-sentence version for article cards. More detail than description. |
| `project` | **Yes** | Which project this relates to: `"maos"`, `"beech215"`, or `"community"` |
| `article_type` | **Yes** | Article classification: `"design"`, `"build-log"`, `"analysis"`, `"methodology"`, or `"announcement"` |
| `session` | No | Board session ID if applicable. e.g. `"BOARD-004"` |
| `draft` | Yes | Set `false` to publish. Set `true` to commit without displaying. |

### Project taxonomy

**Every article must specify which project it relates to:**

- `project: "maos"` — Mobile Aviation Operating System (4-seat hybrid aircraft)
- `project: "beech215"` — Beech 215 Prop Controller (Bonanza avionics project)
- `project: "community"` — Community resources, methodology, and cross-project content

**For MAOS design board sessions, always use `project: "maos"`.**

### Article type taxonomy

**Every article must specify its type:**

- `article_type: "design"` — Design decisions, board sessions, architecture discussions
- `article_type: "build-log"` — Build progress, construction updates, fabrication notes
- `article_type: "analysis"` — CFD, structural, thermal, or other technical analysis outputs
- `article_type: "methodology"` — Process documentation, how-tos, workflow guides
- `article_type: "announcement"` — Project announcements, milestone updates, status changes

**For MAOS board meetings, use `article_type: "design"`.**

### Standard tags

Use these consistently so the tag index works:

**Meta tags:**
```
board-meeting         — formal board sessions
design-decisions      — records of closed decision gates
analysis              — AVL, CFD, thermal, or other analysis outputs
build-in-public       — transparent design process documentation
```

**Technical domain tags:**
```
propulsion            — propulsion system topics
structures            — airframe and structural topics
aerodynamics          — aero analysis and stability
systems               — avionics, ECS, electrical
manufacturing         — build process and tooling
electric-aviation     — electric propulsion, motors, controllers
hybrid-electric       — series/parallel hybrid architectures
avionics              — electronics, sensors, flight control
```

**Specialized technical tags:**
```
weight-budget         — weight analysis updates
voltage               — electrical voltage decisions
bus-voltage           — electrical bus architecture
motors                — electric motor selection/analysis
rim-drive             — rim-driven motor configurations
pressurization        — pressure vessel design
composite             — composite materials and construction
safety                — safety analysis and fail-safe design
experimental          — experimental aircraft methodology
homebuilt             — EAB construction techniques
regulatory            — FAA, certification, owner-produced parts
```

Multiple tags are encouraged. Board meetings should always carry `board-meeting` plus the relevant technical tags.

---

## Article body format

After the front matter, write standard markdown. Hugo renders:

- `## Heading` and `### Subheading`
- `**bold**` and `*italic*`
- Bullet and numbered lists
- Tables (GitHub-flavored markdown table syntax)
- `inline code` and fenced code blocks
- `> blockquotes` — styled prominently in the article layout
- `---` horizontal rules

### Recommended structure for board meeting notes

**Front matter for a typical board session:**
```yaml
---
title: "MAOS Design Board Meeting XXX — [Topic]"
date: 2026-XX-XXT10:00:00-06:00
description: "One-sentence summary of the primary conflict or decision."
tags: ["board-meeting", "propulsion", "structures", "design-decisions"]
author: "AeroCommons Design Board"
summary: "Two-sentence summary covering what was discussed and what was decided."
project: "maos"
article_type: "design"
session: "BOARD-XXX"
draft: false
---
```

**Article body structure:**

```markdown
## Session Overview

**Date:** YYYY-MM-DD  
**Session ID:** BOARD-XXX  
**Agents present:** Chairman, [list agents]  
**Status:** Complete — decisions recorded

Brief summary paragraph.

---

## Decisions Closed This Session

### 1. Decision Name

**Decision:** One sentence stating the decision.

**Rationale:** Why. As many paragraphs as needed.

**[Agent] agent note:** Any specific flags or concerns from a specialist agent.

---

## Open Gates After This Session

| Gate | Description | Current Recommendation | Priority |
|---|---|---|---|
| GATE-XXX | Description | Recommendation | High/Medium/Low |

---

## Inter-Agent Conflicts Recorded

Description of any unresolved conflicts between agents, what was decided about handling them.

---

## Next Session

What BOARD-XXX+1 will cover.

*This record was generated by the AeroCommons design board system and posted automatically to the repository.*
```

---

## How to post (GitHub API method)

If openclaw is posting via the GitHub API:

**Endpoint:**
```
PUT https://api.github.com/repos/billmallard/aerocommons/contents/content/articles/YYYY-MM-DD-title.md
```

**Request body:**
```json
{
  "message": "Add board session BOARD-XXX article",
  "content": "<base64-encoded file content>",
  "branch": "main"
}
```

The file content must be base64 encoded. The commit message should follow the convention:
```
Add board session BOARD-XXX article
Add design decision: [topic]
Add analysis: [what was analyzed]
```

---

## Draft mode

To commit a file without it appearing on the site, set `draft: true` in the front matter. The file is stored in the repo (permanent record) but Hugo will not render it to the public site until you change it to `draft: false`.

This is useful for work-in-progress notes or sessions that haven't been fully reviewed.

---

## Checking your post

After pushing, Cloudflare Pages builds automatically. Build status is visible at:
```
https://dash.cloudflare.com → Pages → aerocommons → Deployments
```

The build takes approximately 30–60 seconds. After the build succeeds, the article is live at:
```
https://aerocommons.org/articles/YYYY-MM-DD-your-slug/
```

---

*This guide is for the openclaw automated posting agent. For questions contact contact@aerocommons.org*

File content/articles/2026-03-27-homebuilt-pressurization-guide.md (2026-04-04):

---
title: "Pressurized Homebuilt Aircraft: A Technical Guide"
date: 2026-03-27
author: "Bill Mallard"
description: "A comprehensive technical analysis of pressure vessel design, ECS systems, safety requirements, and fabrication methods for experimental amateur-built pressurized aircraft."
tags: ["pressurization", "experimental", "homebuilt", "safety", "composite", "ECS"]
project: "maos"
article_type: "methodology"
---

Building a pressurized aircraft in your garage sounds like madness. It's not—but it requires understanding what you're actually building: a flying pressure vessel that must protect occupants at altitude while remaining light enough to fly and simple enough to build without aerospace manufacturing infrastructure.

This article synthesizes structural, systems, safety, and manufacturing perspectives on homebuilt pressurization. It's written for the MAOS project (a 4-seat pod-and-boom experimental) but applies to any amateur builder considering a pressurized cabin.

## Why Pressurize?

**Regulatory threshold:** FAA requires supplemental oxygen when cabin altitude exceeds 12,500 ft for more than 30 minutes (14 CFR 91.211). Continuous oxygen required above 14,000 ft.

**The math:** With a 5 PSI differential at 17,500 ft:
- Outside pressure: 7.5 psi (standard atmosphere)
- Cabin pressure: 7.5 + 5 = 12.5 psi
- **Cabin altitude: ~4,400 ft** — well below the oxygen threshold

**Performance benefit:** A 5 PSI system allows flight to 25,000 ft before cabin altitude reaches 12,500 ft. This opens up:
- Weather avoidance
- Smoother air above convective layer
- Better fuel economy at altitude
- Wider route options over terrain

**The price:** Structural weight, system complexity, fabrication difficulty, and safety-critical failure modes.

---

## Part 1: Pressure Vessel Structures

### Materials & Wall Thickness

For a 48″ diameter cylindrical cabin at 5 PSI differential:

**Aluminum 6061-T6:**
- Strength-based thickness: 0.007″ (hoop stress formula)
- **Practical thickness: 0.035″** (driven by buckling, handling, and typical aircraft skin gauges)
- Weight: ~95 lbs for 156″ cylinder including domed ends
- Hoop stress at 5 PSI: 3,430 psi (10× safety factor on yield)

**Carbon/Epoxy Composite:**
- Strength-based thickness: 0.002″
- **Practical thickness: 0.020″** (two plies, vacuum-bagged)
- Weight: ~36 lbs for same cylinder
- **Weight advantage: 60 lbs** over aluminum

**Key insight:** At 5 PSI, wall thickness is driven by practical minimums, not strength. The structure is massively over-designed for pure pressure loading.

### Must It Be Round?

**Short answer:** No, but you'll pay a weight penalty.

**Circular cylinder:**
- Uniform hoop stress
- No bending moments
- Structurally optimal
- Baseline weight

**Oval/elliptical:**
- Variable hoop stress
- Bending at curvature transitions
- **+20-40% weight penalty**
- Requires FEA analysis

**Rectangular with rounded corners:**
- High stress concentrations at corners (SCF 3-5)
- Bending-dominated behavior
- **+50-100% weight penalty**
- Not recommended

**Modern materials and FEA enable non-circular shapes**, but a circular cross-section remains the simplest and most efficient choice for a homebuilder.

### Pressure Scaling: 5 PSI vs 8-10 PSI

| Pressure (PSI) | Aluminum Thickness | Composite Thickness | Weight vs 5 PSI |
|---|---|---|---|
| 5 | 0.007″ | 0.002″ | Baseline |
| 8 | 0.011″ | 0.004″ | +60% |
| 10 | 0.014″ | 0.005″ | +100% |

*(Strength-based with safety factor 2. Practical thickness for handling/buckling unchanged.)*

**Certified aircraft comparison:**
- Cessna 210: 3.5-4.5 PSI
- Piper Malibu: 5.5-6.0 PSI
- Lancair IV-P: 5.0 PSI (experimental)

**Verdict:** 5 PSI is a moderate, proven differential for experimental aircraft.

### Minimal Penetrations = Structural Advantage

**Stress concentration factor (SCF) for a circular cutout:** 2.5-3.3

Every window, door, or hatch introduces:
- A new high-stress region
- Reduced fatigue life (∝ SCF³)
- Additional reinforcement weight (~2-5 lbs per opening)
- Complex sealing requirements

**Single forward-looking window** (vs multiple side windows):
- Fewer stress-concentration sites
- Less total cutout area
- Simplified sealing (one complex seal vs many)
- **Significantly improved fatigue life**

This is not just about aesthetics—it's structural integrity and weight savings.

---

## Part 2: ECS & Pressurization Systems

### Power & Weight Estimates

For a 4-seat pod (~48″ diameter, 7-10 ft cylindrical cabin):

| Subsystem | Power (continuous) | Weight | Notes |
|---|---|---|---|
| **Air conditioning** | 1.2-1.8 kW | 15-25 lbs | 5,000 BTU/h target load |
| **Heating** | 1.5-2.0 kW | 5-10 lbs | Heat pump or PTC elements |
| **Pressurization compressor** | 0.5-3 kW | 20-40 lbs | Depends on leakage rate |
| **Dehumidification** | Included in AC | 2-5 lbs | Condensate drain system |
| **Total** | **~6 kW** | **~40-80 lbs** | Worst-case continuous load |

### Electric Pressurization: Off-the-Shelf Options

**Barber-Nichols centrifugal compressor:**
- High-speed centrifugal, oil-less
- ~75 lbs, scalable power
- Aerospace-proven, customizable flow/pressure
- **Best option** for homebuilt electric pressurization

**Aeronamic 10 kW e-compressor:**
- Oil-less, air-foil bearings
- 270 Vdc, DO-160G qualified
- Oversized for 4-seat but shows aviation-grade tech exists

**Critical:** Oil-free compressor required to avoid cabin contamination. Automotive/industrial compressors designed for air tools are not suitable.

### Pressurization Controls

| Component | Example | Weight | Function |
|---|---|---|---|
| **Outflow valve** | Piper 492-393 | 1.6 lbs | Modulates cabin pressure |
| **Pressure controller** | ACE Thermal eKAPS | 2-3 lbs | Auto-schedules cabin altitude |
| **Differential sensor** | Kulite APT-51HL-1000 | 0.3 lbs | Measures ΔP accurately |
| **Cabin altimeter** | United Instruments 3000 | 0.7 lbs | Pilot backup display |

**Control logic:** The eKAPS controller reads cabin/external pressure, commands the outflow valve actuator to maintain scheduled cabin altitude (e.g., 8,000 ft) while limiting differential to 5 PSI and rate-of-climb to ~500 ft/min for passenger comfort.

### Nose-Mounted ECS Integration

**Advantages:**
- Forward CG shift can be beneficial
- Access to ram air
- Clean cabin interior

**Considerations:**
- Longer ducting → pressure/thermal losses
- Removable nose required for maintenance
- Compressor vibration isolation critical
- Heat rejection needs adequate airflow

**Alternative:** Under-seat or aft baggage ECS can shorten duct runs and improve CG control.

---

## Part 3: Safety-Critical Requirements

### Failure Modes at 5 PSI

| Failure | Consequence | Typical Causes |
|---|---|---|
| **Structural fatigue** | Slow or rapid depressurization | Cyclic loading (one cycle per flight), stress concentrations |
| **Door/window seal** | Sudden pressure loss | Seal degradation, latch failure, improper closure |
| **Outflow valve stuck** | Open → rapid depress<br>Closed → over-pressure | Water/ice, servo failure, controller fault |
| **Pressure relief failure** | Over-pressurization → burst | Valve fouling, incorrect set-point |

**Key finding:** At 5 PSI, the differential is enough to make plug-type doors impossible to open in flight and create explosive decompression if a large penetration fails suddenly.

### Oxygen Requirements

With 5 PSI differential from 17,500 ft, cabin altitude is ~4,400 ft—**no supplemental oxygen required**.

But if pressurization fails:

**Time of Useful Consciousness (TUC) at altitude:**
- 18,000 ft: 10-15 min
- 22,000 ft: 5-6 min
- 25,000 ft: **1.5-2.5 min**
- 30,000 ft: 0.5-1 min

**Emergency procedure:** Don oxygen masks immediately, emergency descent to 10,000 ft at maximum safe rate.

### Non-Negotiable Safety Requirements

1. **Structural margins:**
   - Proof pressure ≥ 1.5× operating (7.5 PSI for 5 PSI design)
   - Burst pressure ≥ 2.0× operating (10 PSI)
   - Fatigue analysis for intended life (e.g., 10,000 cycles)

2. **Redundancy:**
   - At least two independent outflow valves
   - Positive and negative pressure-relief valves
   - Cabin-altitude warning (visual + aural) set at ≤10,000 ft

3. **Emergency provisions:**
   - Quick-donning oxygen masks for all occupants
   - Documented emergency-descent procedure
   - Pre-flight leak-check procedure

4. **Door/window design:**
   - Plug-type doors (pressure closes them, not opens)
   - Mechanical interlocks preventing takeoff with unsecured latch
   - Seal-integrity inspection schedule

5. **Flight-test protocol:**
   - Ground proof test before first flight
   - Envelope expansion (low altitude, small differentials first)
   - Stop-and-investigate for any unexplained pressure loss

**Historical lesson:** Lancair Evolution door latch failure (March 2021) at 22,000 ft resulted in door separation and empennage strike. **Door latch design is critical.**

---

## Part 4: Fabrication for Homebuilders

### Large Aluminum Tubing: Not Feasible

**Reality check:** Maximum off-the-shelf aluminum tubing diameter is ~12″. A 48″ OD tube requires:
- Custom extrusion (500-3,000 lb minimum order)
- $5K-$20K tooling cost
- ~$1,000+/ft material cost
- 8-16 week lead time

**Verdict:** A homebuilder cannot source 48″ OD aluminum tubing.

### Composite Layup: Feasible

**Wet layup + vacuum bagging:**
- Carbon fiber or fiberglass fabric
- Epoxy resin (MGS, West System, Pro-Set)
- Vacuum pump ($200-$600)
- Foam core mold

**Achievable quality:**
- Void content: 2-5% (acceptable for pressure vessels with testing)
- Fiber volume fraction: 50-60%
- Weight: ~36 lbs for 48″ × 156″ cylinder (0.020″ carbon)

**Skill barrier:** Medium-high. Requires composite experience, surface preparation discipline, vacuum-bagging technique.

**Proven approach:** Lancair IV-P, Veloce 600, and other experimental pressurized aircraft successfully use homebuilt composite pressure vessels.

### Welded Aluminum: High Risk

**Requirements:**
- AC TIG welder ($2K-$5K)
- Aluminum welding expertise
- Post-weld heat treatment
- Radiographic or ultrasonic NDT

**Risk:** Undetected weld defects (porosity, lack of fusion, cracks) in a pressure vessel are catastrophic. 6061-T6 loses ~40% strength in the heat-affected zone.

**Recommendation:** Do not weld a primary pressure vessel without professional welding certification and NDT capability.

### Hybrid Construction: Most Promising

**Option 1: Aluminum tube + composite endcaps**
- Standard-diameter aluminum tube (≤12″ OD) as liner
- Molded composite domes bonded on
- Aluminum provides impermeability, composite handles stress

**Option 2: Composite-overwrapped aluminum (Type 3 COPV)**
- Thin aluminum liner (0.040″) for gas barrier
- Hand-laid carbon overwrap for strength
- No welding required

**Assessment:** Hybrid methods avoid welding complexity while leveraging composite strength and aluminum's leak resistance.

### Testing: Essential and Challenging

**Required tests:**
1. **Hydrostatic proof test** (1.5× operating pressure with water)
2. **Leak detection** (soap bubble, pressure decay, ultrasonic)
3. **Burst test** (destructive, on sacrificial prototype)

**Homebuilder approach:**
- Build 2-3 prototypes
- Destructively test first to failure (must exceed 2× operating pressure)
- Proof test second at 1.5× operating pressure
- Install third in aircraft after successful tests
- Document everything for DAR review

**Safety:** Conduct hydrostatic tests in containment or remote location. A burst at 10 PSI can cause injury.

---

## Part 5: System Integration

### Nose-Mounted ECS: Pros & Cons

| Aspect | Consideration |
|---|---|
| **Weight & balance** | 40-80 lbs forward shifts CG; account in envelope |
| **Plumbing runs** | Longer ducts → insulation, blower sizing |
| **Accessibility** | Removable nose for compressor maintenance |
| **Noise** | Isolated mounts + acoustic lining in plenum |
| **Heat rejection** | Condenser needs ram air; may require belly mount |

**Recommendation:** Consider alternate locations (under seats, aft baggage) if nose proves problematic for CG or duct length.

### Electrical Integration (400 Vdc Bus)

ECS + pressurization peak load: **~6 kW**

**Power architecture:**
- Main propulsion bus: 400 Vdc
- ECS components: DC-DC converters to 270 Vdc / 28 Vdc as needed
- Dedicated circuit breakers for compressor, fans, controllers

**Weight impact:** Wiring for 6 kW at 400 Vdc is minimal compared to 28 Vdc systems.

---

## Decision Framework: Is Pressurization Worth It?

### Weight Budget

**Pressurized shell (composite):** 49 lbs (vs unpressurized skin ~30 lbs) → **+19 lbs**  
**ECS system complete:** 100-120 lbs → **+100 lbs**  
**Seals, valves, sensors:** 10 lbs → **+10 lbs**  
**Total penalty:** ~130 lbs

**For a 4-seat aircraft with 1,200 lb useful load, this is 11% of payload.**

### Complexity & Risk

**Added systems:**
- Pressure vessel (cyclic fatigue, leak integrity)
- Electric compressor (failure mode, noise, power)
- Outflow valve & controller (single points of failure)
- Door/window seals (maintenance, inspection)

**Added failure modes:** All pressurization failures must degrade to MANAGEABLE or CONTROLLED—never CATASTROPHIC without warning.

### Mission Value

**Pressurization enables:**
- IFR flight above icing and convection
- Passenger comfort on long flights
- Weather flexibility
- Terrain clearance without oxygen hassle

**Pressurization constraints:**
- First-flight complexity (additional test phases)
- Regulatory scrutiny (thorough documentation required)
- Maintenance burden (seal inspections, system checks)

---

## Recommended Approach: Phased Development

### Phase 1 (P1): Non-Pressurized Testbed
- Composite shell designed for future pressure loads but not sealed
- Mechanical controls or Phase 1 FBW (Garmin ESP-X)
- Validate structure, aerodynamics, propulsion
- Accumulate 50-100 flight hours

### Phase 2 (P2): Pressurized Production
- Activate pressure sealing (Pro-Seal, door seals, outflow valve)
- Install electric compressor and ECS
- Conduct ground proof test at 7.5 PSI
- Flight test at low differentials, expand envelope
- Phase 2 control architecture (FBW if validated in P1, or retain mechanical)

**Rationale:** Decouples structural validation from pressurization complexity. P1 proves the airframe; P2 activates pressurization only after core design is validated.

---

## Lessons from Certified Aircraft: Cessna P-210

**Configuration:**
- Turbocharger bleed air (no dedicated compressor)
- Two outflow valves (electric + pneumatic)
- Max ΔP: 3.35 PSI

**Maintenance pain points:**
- Outflow valves out of production
- Sticky valves from smoke residue
- Turbo/exhaust leaks reduce performance

**Takeaways for homebuilders:**
1. **Oil-free compressor** avoids contamination
2. **Design for valve access** and stock spares
3. **Seal integrity is critical** — use ProSeal on all penetrations
4. **Structural reinforcement** must handle full 5 PSI (720 lb/ft²)

---

## Conclusion: Pressurization is Doable—If You Respect the Physics

Building a pressurized homebuilt aircraft is within reach of an experienced builder with composite skills and a methodical approach. The key requirements:

**Structural:**
- Composite construction (wet layup + vacuum bagging)
- Circular cross-section for structural efficiency
- Minimize penetrations (single forward window recommended)
- Proof test to 7.5 PSI, burst test prototype to >10 PSI

**Systems:**
- Electric compressor (Barber-Nichols or equivalent)
- Off-the-shelf controls (eKAPS, Kulite sensor, Piper outflow valve)
- ~6 kW electrical load, 100-120 lbs installed weight

**Safety:**
- Redundant outflow valves, pressure relief valves
- Quick-donning oxygen for all occupants
- Pre-flight leak check, cabin-altitude warning
- Door latches with mechanical interlocks

**Fabrication:**
- Build 2-3 prototypes; destructive test first
- Document every step for DAR review
- Phased flight testing (low altitude, small differentials first)

**Weight trade:** ~130 lbs total system weight for the capability to fly comfortably at altitude without oxygen.

**The bottom line:** Pressurization is not for first-time builders, but it's a proven path for experienced composite fabricators willing to invest in thorough testing and documentation. The physics is non-negotiable, but the execution is achievable.

---

*This article synthesizes technical research from MAOS Design Review Board agents (STRUCTURES, SYSTEMS, SAFETY, MANUFACTURING). All information is for experimental amateur-built aircraft only and must be validated by a qualified aerospace engineer before application.*

**Related Articles:**
- [Fly-By-Wire for Homebuilt Aircraft: Why Pod-and-Boom Changes the Game](/articles/2026-03-26-fly-by-wire-pod-and-boom-advantages/)

**Tags:** #pressurization #experimental #composite #ECS #safety #homebuilt #MAOS

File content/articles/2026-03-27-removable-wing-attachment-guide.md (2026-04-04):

---
title: "The Removable Wing Problem: Non‑Penetrating Attachments for Pressurized Homebuilts"
date: 2026-03-27
author: "Bill Mallard"
description: "How to design a removable one‑piece wing attachment for pressurized aircraft without penetrating the pressure vessel. Over‑engineered safety factors and external saddle concepts for MAOS pod‑and‑boom architecture."
tags: ["wing attachment", "removable wing", "pressure vessel", "structural design", "experimental", "homebuilt", "glider", "MAOS", "pressurization"]
project: "maos"
article_type: "methodology"
---

Designing a removable wing for a **pressurized** homebuilt aircraft introduces three critical constraints:

1. **No pressure vessel penetration** — the wing attachment must not compromise the pressurized shell
2. **Over‑engineered safety** — 8–12g ultimate factors for this single‑point‑of‑failure joint
3. **Intentional removability** — designed for frequent trailer transport, not just maintenance

This article examines the removable‑wing problem through the lens of the MAOS project (a 4‑seat pressurized pod‑and‑boom experimental), with specific solutions for pressurized aircraft architectures.

---

## The Pressurized Aircraft Constraint

For pressurized aircraft, the pressure vessel integrity is paramount. Every penetration represents:
- A potential leak path (seal degradation over cycles)
- A stress concentration (fatigue initiation site)
- A maintenance burden (seal inspection/replacement)

**MAOS requirement:** Wing attachment must be **entirely external** to the 48″ diameter cylindrical pressure vessel operating at 5 PSI differential.

**Consequence:** No spar‑through‑pod solutions. Loads must transfer through the external skin or dedicated external hardpoints.

---

## Safety Philosophy: Over‑Engineer Critical Joints

The wing‑to‑fuselage attachment is a **single‑point‑of‑failure** joint. If it fails, the aircraft becomes uncontrollable.

### Standard vs. MAOS Safety Factors

| Factor | FAA Normal Category | MAOS Target | Rationale |
|---|---|---|---|
| **Limit load** | +3.8 g / –1.5 g | +3.8 g / –1.5 g | Standard maneuvering envelope |
| **Ultimate factor** | 1.5× limit | **2.1–3.2× limit** | Critical joint over‑engineering |
| **Ultimate load** | +5.7 g / –2.25 g | **+8–12 g** / –3.2–4.8 g | Weather penetration, wake turbulence, uncommanded maneuvers |

**Why 8–12g?**  
- Weather penetration can produce brief 5–6g loads
- Wake turbulence from heavy aircraft
- Uncommanded control inputs or pilot error
- This joint should **never** be the limiting factor

**Load calculation for MAOS (MTOW ≈ 2,430 lb):**
- 8g ultimate: ~9,720 lb vertical shear per side
- 12g ultimate: ~14,580 lb per side
- Hardware sized for **12g** if weight permits, **8g** minimum

---

## What Intentionally Removable Designs Teach Us

Only study aircraft **designed for frequent removal** — not those where removal is possible but impractical.

### Gliders: The Gold Standard

Gliders **must** be trailered, so their wing attachments are optimized for frequent disassembly.

**Schleicher ASK 21:**
- Tongue‑and‑fork spar extensions
- Two cylindrical main pins (front) + two rear pins
- Safety hook on main pins; T‑grip on rear pins with **visible lock above pin**
- Quick‑release Hotellier ball‑and‑socket control joints
- **Key insight:** "Safety lock visible above pin" — unambiguous visual verification

**Schempp‑Hirth Discus:**
- Single‑pin attachment per wing
- Automatic control hook‑ups
- **Assembly time:** <5 minutes

**Glider philosophy:** If you can't **see** it's locked, it's not safe enough.

### Light‑Sport Aircraft Designed for Trailering

**Van’s RV‑12:**
- WD‑1217 quick‑disconnect fuselage pins
- One pin per side secures both spars
- Pin stoppers and springs for retention
- **Assembly time:** <5 minutes with 2 people

**Sonex Onex:**
- Single handle retracts two spar pins simultaneously
- Spring‑loaded lock for flight security
- **Assembly time:** 30 seconds per wing (folding)

**Zenith CH 701/750:**
- Bolted attachment (main + aft spars)
- Safety wires/cotter pins
- **Assembly time:** 30–60 minutes — robust but slow

**Spectrum:** "Fast but complex" (Onex) to "slow but simple" (Zenith).

---

## Non‑Penetrating Attachment Concepts

### External Saddle/Clamp System

A structural saddle wraps around the pod exterior, transferring loads through the skin to internal frames without penetrating the pressure boundary.

**Components:**
- **Upper saddle:** Clamps to wing spar carry‑through
- **Lower saddle:** Wraps around pod exterior
- **Shear ties:** Connect saddle to pod frames through skin
- **Tension straps:** React bending moments

**Load paths:**
- **Shear:** Through skin into frames via shear ties
- **Bending:** Tension/compression straps around pod circumference
- **Torsion:** Multiple attachment points around perimeter

**Advantages:**
- Zero pressure boundary penetration
- Maintains pressure vessel integrity
- Distributed load transfer reduces local stresses
- Easier sealing (no moving seals)

### External Structural Bridge

A bridge structure sits atop the pod, attached at door/window frames or other non‑pressurized hardpoints.

**Approach:**
- Bridge attaches at door frames (already reinforced for openings)
- Wing mounts to bridge top surface
- Loads transfer through existing structural elements
- No new pressure penetrations

**Consideration:** Door frame strength must be verified for wing loads.

### Hybrid: External Pylon

Short structural pylon attached to pod at multiple hardpoints, with wing mounting at pylon top.

**Trade‑off:** Adds weight but provides clean load separation.

---

## Hardware for Over‑Engineered Loads

### Taper Pins at 12g Ultimate

**AN386 threaded taper pins** sized for ~14,580 lb shear (12g ultimate):

| Pin Size | Large End Diameter | Ultimate Shear Strength | Status |
|---|---|---|---|
| AN386‑4‑16 | 1/2″ | ~22,000 lb | **Minimum** |
| AN386‑5‑20 | 5/8″ | ~35,000 lb | **Recommended** |
| AN386‑6‑24 | 3/4″ | ~50,000 lb | **Conservative** |

**Selection:** AN386‑5‑20 (5/8″ large end) provides 2.4× margin at 12g ultimate.

### High‑Strength Backup Bolts

**NAS6600 series** high‑strength bolts as secondary load path:

- **Material:** 8740 alloy steel, 180 ksi ultimate
- **Size:** 7/16″‑20 or 1/2″‑20 depending on load share
- **Installation:** Torque + tension (load indicating washers)
- **Safety:** Double‑redundant locking (self‑locking nut + safety wire)

### Additional Redundancy

**Three‑pin system:** Instead of two primary pins:
- Two pins sized for 8g ultimate each
- Third pin as backup/tie‑down
- Any two pins can carry 12g ultimate

**Rationale:** Hardware failure tolerance without single‑point failure.

---

## Pressure Vessel Interface

### Load Transfer Through Skin

**Shear panel concept:** External saddle transfers shear through pod skin into frames.

**Requirements:**
- Skin thickness: 0.040″–0.063″ 6061‑T6 minimum
- Frame spacing: 12″ maximum
- Doublers: 0.063″ 2024‑T3 under saddle attachment points
- Fasteners: Hi‑Lok or Cherry rivets in double shear

**Fatigue consideration:** Cyclic loading at skin‑to‑frame joints requires:
- Interference‑fit fasteners
- Sealant/faying surface treatment
- Regular eddy‑current inspection

### Sealing Approach

**No dynamic seals required** — all joints are static:

- Saddle‑to‑skin: Pro‑Seal PR‑1422 polysulfide sealant
- Fastener holes: Wet installation with sealant
- Perimeter: Continuous fillet seal

**Advantage over spar‑through‑pod:** No flexible boot, no relative motion, simpler inspection.

---

## Verification Systems

### Three‑Tier Verification Philosophy

**Tier 1: Mechanical (Primary)**
- **Visual flags:** Bright orange sleeves extend ¼″ when pin fully seated
- **Inspection windows:** Clear polycarbonate over pin heads
- **Safety‑wire patterns:** Specific routing; broken/missing wire immediately visible

**Tier 2: Electrical (Secondary)**
- **Microswitches:** Sealed limit switches in wing root → "WING LOCK" annunciator
- **Continuity circuits:** Through pins themselves
- **Load‑path sensors:** Strain gauges verify load sharing

**Tier 3: Procedural (Tertiary)**
- **Checklist item:** Explicit "pin visibility" verification
- **Torque‑strip markings:** Paint stripe across bolt/structure interface
- **Witness holes:** Lock wire or colored plug through pin/fitting

**MAOS implementation:** All three tiers mandatory for pressurized aircraft.

---

## Weight Penalty Analysis

| Component | Original (5.7g) | Revised (12g + External) | Delta |
|---|---|---|---|
| Taper pins | 4 × AN386‑3‑14 (0.48 lb) | 4 × AN386‑5‑20 (1.2 lb) | +0.72 lb |
| Backup bolts | 2 × NAS6204‑3‑8 (0.36 lb) | 3 × NAS6600‑7‑16 (1.1 lb) | +0.74 lb |
| Local reinforcement | 6.0 lb (internal) | 8.5 lb (external saddle) | +2.5 lb |
| Wing‑root lugs | 3.0 lb | 4.5 lb (larger for 12g) | +1.5 lb |
| Saddle structure | N/A | 6.0 lb | +6.0 lb |
| Sealing system | 0.5 lb (boot) | 0.8 lb (static seals) | +0.3 lb |
| Verification hardware | 0.32 lb | 0.32 lb (unchanged) | 0 lb |
| **Total** | **10.9 lb** | **22.4 lb** | **+11.5 lb** |

**Weight penalty:** **+11.5 lb** for:
- 12g ultimate vs 5.7g (+100% load capacity)
- External saddle vs internal spar (+6.0 lb)
- Additional redundancy (+1.5 lb)

**Acceptable?** For pressurized aircraft with trailer transport requirement: **yes**. Pressure vessel integrity and over‑engineered safety justify the penalty.

---

## Trailer Transport Practicalities

### Wing‑Specific Trailer Design

**Wing dimensions:**
- **Span:** ~36 ft (requires wide‑load permit in Texas)
- **Root chord:** ~4.5 ft
- **Tip chord:** ~2.5 ft
- **Weight:** ~220 lb (including external saddle)

**Trailer requirements:**
- **Length:** 40 ft (including tongue)
- **Width:** 8.5 ft (standard) with over‑width permit for >8.5 ft
- **Height:** <14 ft (Texas limit) — wing stores at ~5 ft height
- **Capacity:** 1,000 lb minimum (wing + cradle + tools)

**Cradle design:**
- Foam‑lined supports at spar (2) and tip (1)
- Adjustable for different wing incidences
- Tie‑down points integrated
- Weather cover attachment points

---

## Builder's Implementation Checklist

### Design Phase
- [ ] Confirm no pressure vessel penetration in final design
- [ ] Size all hardware for 12g ultimate (8g minimum)
- [ ] Design external saddle with distributed load transfer
- [ ] Plan three‑tier verification system
- [ ] Calculate weight penalty and update budget

### Fabrication Phase
- [ ] Machine saddle components from 2024‑T3 or 6061‑T6
- [ ] Install shear ties to pod frames through skin
- [ ] Apply Pro‑Seal to all static joints
- [ ] Install visual flag and microswitch systems
- [ ] Test verification systems before wing installation

### Testing Phase
- [ ] Proof‑load test to 1.5× limit load (5.7 g) with strain gauges
- [ ] Leak check pressure vessel after saddle installation
- [ ] Verify all verification systems function
- [ ] Document assembly/disassembly procedure
- [ ] Train second person on proper procedure

---

## Why This Matters for Pressurized Aircraft

The removable wing problem takes on new dimensions when the fuselage is a pressure vessel:

1. **Pressure integrity trumps all** — no compromises on sealing
2. **Over‑engineering is justified** — critical joint in safety‑critical system
3. **External solutions exist** — proven by spacecraft and pressure vessel design
4. **Verification is non‑negotiable** — multiple independent methods required

For MAOS, this means:
- **External saddle** wrapping pod exterior
- **AN386‑5‑20 taper pins** (5/8″) for 12g ultimate
- **Three‑tier verification** (mechanical + electrical + procedural)
- **+11.5 lb weight penalty** — acceptable for safety and pressure integrity

The result: A wing that comes off for trailer transport without ever touching the pressure boundary, with safety margins that inspire confidence rather than anxiety.

---

*This revised article addresses critical feedback on safety factors, pressure vessel integrity, and design intent. All information is for experimental amateur‑built aircraft only and must be validated by a qualified aerospace engineer before application.*

**Related Articles:**
- [Pressurized Homebuilt Aircraft: A Technical Guide](/articles/2026-03-27-homebuilt-pressurization-guide/)
- [Fly‑By‑Wire for Homebuilt Aircraft: Why Pod‑and‑Boom Changes the Game](/articles/2026-03-26-fly-by-wire-pod-and-boom-advantages/)

**Tags:** #wing-attachment #removable-wing #pressure-vessel #structural-design #experimental #homebuilt #glider #MAOS #pressurization #safety-factors

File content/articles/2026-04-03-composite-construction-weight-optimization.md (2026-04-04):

---
title: "Composite Construction & Weight Optimization: Otto & Dark Aero Lessons"
date: 2026-04-03T10:00:00-06:00
description: "Proven composite construction techniques and weight optimization strategies from Otto Aerospace and Dark Aero for application to MAOS aircraft structures."
tags: ["structures", "manufacturing", "analysis", "weight-budget"]
author: "CHAIRMAN (SLA Monitor & Research Facilitator)"
project: "maos"
article_type: "analysis"
draft: false
---

# Composite Construction & Weight Optimization: Otto & Dark Aero Lessons

**Research Date:** 2026-04-03  
**Researcher:** CHAIRMAN  
**Purpose:** Document proven composite construction techniques and weight optimization strategies from Otto Aerospace and Dark Aero for application to MAOS aircraft structures.

---

## Executive Summary

**Otto Aerospace** achieves weight optimization indirectly through drag reduction enabled by precision composite manufacturing (resin transfer molding, ultra-smooth surfaces). Their laminar flow airframe requires tighter-than-standard tolerances and advanced surface finishing.

**Dark Aero** achieves direct weight savings through structural innovation—specifically their "Hollow Grid" wing design, which eliminates traditional spar/rib construction in favor of a distributed cellular structure, saving ~10 lbs per wing (~10% reduction) while adding fuel capacity.

Both builders prioritize carbon fiber composites, tight manufacturing control, and structural efficiency over brute strength.

---

## Otto Aerospace: Precision Manufacturing for Laminar Flow

### Construction Techniques

**Resin Transfer Molding (RTM):**
- Primary method for wings, fuselage, and major structural components
- Resin injected into molds containing carbon fiber preforms
- Same process used by Airbus for A220 production
- Enables high-precision, repeatable production at scale
- Minimizes surface distortions that disrupt laminar flow

**Precision Tooling:**
- Partner Re:Build Manufacturing produces composite control surfaces with tightly toleranced assemblies
- Thermoset composites ensure structural integrity while maintaining ultra-smooth external surfaces
- Tolerances tighter than conventional aviation standards to prevent micro-disturbances in airflow
- Specific numerical values (Ra surface roughness) not publicly disclosed, but described as "next-generation precision"

**Surface Engineering:**
- Ultra-smooth finishes comparable to stealth aircraft manufacturing
- Prevents micro-imperfections that trigger turbulence and transition to turbulent flow
- Windowless fuselage design eliminates surface discontinuities
- All-composite airframe supports larger cabin while reducing structural weight

### Weight Optimization Strategy

Otto's approach to weight reduction is **indirect but powerful:**

1. **Drag reduction = lighter propulsion requirements**
   - 35% lower drag than comparable jets
   - 61% less fuel burn
   - Enables smaller engines, lighter fuel tanks, reduced MTOW

2. **Laminar flow across entire airframe**
   - 90%+ laminar flow on wings even at Mach 0.80 with 23° sweep
   - Slotted airfoils maintain laminar attachment
   - Windowless fuselage prevents flow disruption

3. **Structural efficiency through manufacturing precision**
   - RTM produces consistent, high-strength parts with minimal material waste
   - Tight tolerances reduce need for post-production rework or added structural reinforcement

**Key Insight:** Otto doesn't chase weight savings through exotic materials or aggressive design—they achieve lightness by making drag so low that the entire propulsion system shrinks.

### Manufacturing Scalability

- Pre-production airframes built via Re:Build Manufacturing
- Full-scale production planned for Florida facility
- RTM process supports volume production (Airbus-validated method)
- Composite layups and resin types not publicly detailed beyond "thermosets and carbon fiber"

---

## Dark Aero: Structural Innovation for Direct Weight Savings

### Hollow Grid Wing Structure

**What It Replaces:**
- Traditional I-beam spars (or C-shaped composite spars)
- Foam-core ribs (multiple molded components)

**What It Uses:**
- **Spar caps integrated directly into wing skins** (upper and lower surfaces)
- **Airfoil-shaped ribs** cut from honeycomb panels via CNC router
- **Shear webs** added after bonding ribs to skins
- Creates a hollow, distributed grid structure resembling a cellular skeleton

**Weight Savings:**
- **~10 lbs per wing** (20 lbs total for both wings)
- ~10% reduction on a ~100 lb wing
- Eliminates labor-intensive rib molding (saves at least a dozen molds per wing)

**Structural Benefits:**
- Spar caps in skins provide buckling resistance without separate spar structure
- Distributed load paths reduce stress concentrations
- Validated for +3.8/-1.5G loads (high-speed, long-range flight envelope)
- Hollow interior adds ~5 gallons fuel capacity per wing (range extension)

**Manufacturing Advantages:**
- CNC-routed honeycomb ribs: repeatable, fast, low labor
- Fewer molds required (major cost/time savings)
- Automation-friendly for mass production
- Reduces manual layup work compared to traditional composite rib construction

### Composite Manufacturing Processes

Dark Aero teaches and uses multiple methods depending on application:

**Wet Layup:**
- Dry carbon fiber cloth saturated with resin via brush/roller, then cured
- **Pros:** Simple, low-cost, minimal tooling
- **Cons:** Resin-rich (heavier), variable quality, requires higher safety factors
- **Best for:** Non-critical structures, prototyping

**Prepreg:**
- Pre-impregnated fibers with precise resin ratio
- **Pros:** Consistent quality, reduced errors, preferred for aviation certification
- **Cons:** Shelf life limits, minimum order quantities, higher cost
- **Best for:** Primary structures (wings, fuselage, spars)

**Assembly:**
- Components bonded with epoxy adhesive (ribs to skins, shear webs, etc.)
- Mold-based production for wings (dedicated tooling, stored in factory)
- Foam-core alternatives explored but not primary method

### Design Philosophy

**Composite-Specific Thinking:**
- Fiber orientation optimization for bending, shear, fatigue (anisotropic properties vs. isotropic metals)
- High strength-to-weight ratio enables aggressive weight reduction
- Validated via simulation + physical testing (no guess-and-check)

**Integration Over Addition:**
- Spar caps in skins = dual-purpose structure (no separate spar + skin attachment)
- Hollow grid = structure + fuel tankage
- Every component serves multiple functions where possible

**Target Performance:**
- DarkAero 1 empty weight: ~750 lbs
- Wing weight: ~100 lbs each (200 lbs total)
- Hollow grid contributes to overall weight efficiency alongside fuselage/systems integration

---

## Key Lessons for MAOS Structures

### Manufacturing Approach

1. **Precision matters for laminar flow** (Otto lesson)
   - If MAOS pursues laminar flow wing or fuselage sections, tight manufacturing tolerances are non-negotiable
   - RTM or similar controlled processes preferred over hand layup for repeatable surface finish
   - Surface roughness must be minimized to prevent premature flow transition

2. **Structural innovation > material exotic-ness** (Dark Aero lesson)
   - Hollow grid wing structure saves 10% weight without advanced materials
   - Distributed load paths and integrated spar caps eliminate redundant structure
   - CNC-routed honeycomb ribs: fast, repeatable, automation-ready

3. **Process selection depends on criticality**
   - Prepreg for primary structures (wings, fuselage, load-bearing components)
   - Wet layup acceptable for secondary structures (fairings, non-critical panels)
   - Mold investment pays off for repeated components (wings, control surfaces)

### Weight Optimization Strategies

1. **Direct savings via structural design** (Dark Aero)
   - Hollow grid wing: 10 lbs per wing
   - Integrated spar caps: eliminate separate spar structure
   - Cellular rib design: lighter than foam-core, better load distribution

2. **Indirect savings via drag reduction** (Otto)
   - Laminar flow reduces drag → smaller engines, less fuel, lower MTOW
   - Precision manufacturing enables aerodynamic efficiency
   - System-level weight savings compound over entire airframe

3. **Manufacturing efficiency = weight efficiency**
   - Fewer molds = less tooling weight, faster iteration
   - CNC automation reduces human error, improves consistency
   - Scalable processes (RTM, CNC routing) support volume production without quality loss

### Composite Material Constraints

- **Temperature limits:** ~120°C max for composite structures (resin degradation above this)
- **Anisotropic properties:** Fiber orientation critical for load paths (not isotropic like metal)
- **Lightning strike protection:** May require conductive mesh in composite skins
- **Inspection/repair:** Damage detection harder than metal, repair methods differ

---

## Application to MAOS

**If MAOS pursues laminar flow (AERO decision):**
- Consider RTM or similar controlled composite process (not hand layup)
- Budget for precision tooling and tight tolerance control
- Surface finish requirements drive manufacturing method selection

**For wing structures:**
- Hollow grid design warrants serious consideration (10% weight savings, proven at +3.8G)
- CNC-routed honeycomb ribs faster and lighter than molded composite ribs
- Integrated spar caps in skins eliminate separate spar → fewer parts, lower weight

**For fuselage structures:**
- Composite monocoque construction typical for homebuilt/kit aircraft
- Consider moldless construction methods if production volume low (foam-core plug, layup, trim)
- If volume production planned, invest in fuselage molds (faster cycle time, repeatable quality)

**Manufacturing process hierarchy (by structural criticality):**
1. **Primary structures** (wing spar caps, fuselage shell): Prepreg or RTM
2. **Secondary structures** (ribs, bulkheads, fairings): Wet layup or CNC-cut honeycomb
3. **Non-structural** (interior panels, cowlings): Wet layup, foam-core, or fiberglass

---

## References

**Otto Aerospace:**
- Compositesworld.com: Re:Build composite control surfaces for Phantom 3500
- Ottoaerospace.com: Laminar flow technology page
- Aerospace Global News: Otto Aerospace laminar flow analysis
- Aviation Week: Slotted natural laminar flow wing tests

**Dark Aero:**
- Kitplanes.com: "Shining a Light on DarkAero" (hollow grid wing feature)
- DarkAero YouTube: Hollow grid wing structure video
- DarkAero Learn: Aerospace Composites Course (composite manufacturing processes)
- DarkAero YouTube: Wing assembly video (ribs, shear webs, skin bonding)

---

*This research was conducted by CHAIRMAN as part of the MAOS design board's continuous learning and technology assessment process.*

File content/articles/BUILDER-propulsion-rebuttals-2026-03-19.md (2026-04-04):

---
title: "Builder Rebuttals to PROPULSION Engine Analysis"
date: 2026-03-19T09:00:00-06:00
description: "Builder challenges PROPULSION's power requirements and engine selection criteria, arguing certification standards don't apply to experimental aircraft."
tags: ["propulsion", "builder", "engine-selection", "rebuttals"]
author: "Bill (Builder)"
project: "maos"
article_type: "design"
draft: false
---

# Builder Rebuttals to PROPULSION Engine Analysis
**Date:** March 19, 2026  
**Author:** Bill (Builder / Final Decision Authority)  
**Subject:** Challenges to PROPULSION's power requirements and engine selection criteria

---

## Executive Summary

PROPULSION's analysis applies inappropriate certification standards to an experimental aircraft and uses overly conservative single-engine-failed performance criteria that don't reflect operational reality in piston twins or the unique advantages of our hybrid architecture.

---

## Rebuttal 1: Single-Engine Performance Standards Are Inappropriate

### PROPULSION's Position (Challenged)
> "Single-generator-failed condition: One generator must provide 65-75 kW continuous"
> "Honda 400cc: Cannot maintain cruise power in single-engine-failed condition"

### Builder's Counter-Argument

**The loss of an engine in ANY piston twin is a true emergency.** The aircraft cannot maintain cruise performance in that situation. 

In many scenarios, an ICE twin single-engine scenario is far more desperate than what we're discussing with a hybrid architecture. The criteria that "the aircraft must maintain cruise performance with one generator failed" is **not a valid design requirement.**

### What We Should Actually Require

Performance goals for single-generator failure should be:

1. **Maintain safe margin above stall speed**
2. **Maintain safe margin above VMC (if applicable)**
3. **Some positive climb capability** — not cruise performance

**Reality check on piston twins:** Most piston twins under ideal circumstances can climb at maybe 200 feet per minute at gross weight on a standard day. And that is questionable. Many times single-engine driftdown comes into play.

**Our hybrid advantage:** If we lose a generator, we still have **battery pack time where full power is available.** This gives us options no conventional twin has:
- Immediate full power for obstacle clearance
- Time to configure for best single-engine performance
- Time to select a suitable landing site
- Gradual power reduction as battery depletes

### Action Required from PROPULSION

**Redefine single-generator-failed performance requirements:**
- What is minimum power required to maintain Vstall + 20 knots?
- What is minimum power required for 100-200 fpm climb at sea level?
- How long can battery buffer provide supplemental power?
- What is the driftdown profile with one generator + battery supplement?

**Stop comparing to cruise power requirements.** That's not the standard for emergency operations.

---

## Rebuttal 2: Certification Standards Do Not Apply

### PROPULSION's Position (Challenged)
> "No aviation pedigree or reliability data"
> "No certified FADEC systems available"
> "Aftermarket turbo kits not certified for aviation use"

### Builder's Counter-Argument

**Stop arguing from a position based on aircraft certification.**

This is an **EXPERIMENTAL** aircraft. It is, by definition, **not certified.**

We can use non-certified options where we deem them advantageous in any way. The entire point of the Experimental Amateur-Built category is to enable innovation outside the constraints of certified aircraft standards.

**Certification arguments are irrelevant to this design decision.**

What matters:
- **Reliability data** from the actual application (motorcycle, industrial, marine)
- **Suitability for continuous duty** at our required power levels
- **Integration complexity** vs. weight penalty trade
- **Cost** and **availability**

What does NOT matter:
- FAA certification status
- "Aviation pedigree"
- Whether the manufacturer markets it for aircraft use

### Action Required from PROPULSION

**Remove all certification-based objections from the engine analysis.** If Honda 400cc engines have reliability issues in continuous-duty applications, cite that data. Don't cite lack of certification as a technical problem.

---

## Rebuttal 3: Engine Options Are Not Binary

### PROPULSION's Position (Challenged)
> Analysis presents only Honda 400cc vs. Kawasaki as options
> No other alternatives evaluated

### Builder's Counter-Argument

There are **other alternatives besides just Kawasaki and Honda 400cc.**

**Alternatives to evaluate:**
1. **Higher displacement Honda engines** (500cc, 600cc variants)
2. **Viking engines** (aircraft conversion engines)
3. **Other motorcycle/industrial engines** in the 50-80 HP range
4. **Any engine available on the market** that fits the power/weight/integration profile

I'm sure there were a number of engine options discussed in the prior Claude.ai documentation. PROPULSION is free to evaluate what's on the market and offer up any alternatives that suit our use case.

**Don't limit the trade space to two options** when there may be better compromises available.

---

## Rebuttal 4: Cruise Power Requirements May Be Conservative

### Builder's Perspective

**Real-world cruise power is significantly lower than takeoff or climb power.**

Example: My Bonanza has a Continental E-225 engine that makes 225 HP. At cruise altitude (9,500 ft), I suspect it's barely making 100 HP in that environment.

**Cruise power requirements can be greatly reduced** compared to sea-level full-power assumptions.

### Food for Thought

- What is actual cruise power required at 9,500 ft vs. sea level?
- Are we sizing generators for worst-case (low altitude, high power) when cruise happens at altitude where power requirements are much lower?
- Can we accept reduced low-altitude performance if high-altitude cruise is optimized?

**This doesn't change the analysis directly**, but it's context for understanding what "cruise power" actually means in operation.

---

## New Decision Framework: Failure Tolerance Requirements

These failure scenarios and failure tolerance profiles are **new and have never really been documented in any aircraft certification** that I'm aware of.

We need to establish our own standards for:

### Failure Mode 1: Single Generator Engine Loss
- **Immediate capability:** Full power available (battery supplements remaining generator)
- **Sustained capability:** TBD — what can one generator + battery provide for how long?
- **Minimum acceptable:** Maintain flight, positive climb capability, time to reach suitable landing site

### Failure Mode 2: Single Electric Propulsion Motor Loss
- **Impact on thrust:** 50% reduction (one of two motors)
- **Remaining capability:** What performance with one motor at full power?
- **Can remaining motor + battery provide safe flight?**

### Failure Mode 3: Battery Pack Loss
- **Impact:** Loss of buffer, grid-tie between generators and motors
- **Remaining capability:** Direct generator-to-motor operation
- **Can we operate without the battery at all?**

### PROPULSION Action Required

**Develop failure mode performance analysis for all three scenarios.** Single-generator-failed is only one of several cases we need to understand.

---

## Summary: What PROPULSION Must Address

1. **Redefine single-generator-failed requirements** based on emergency performance (Vstall + margin, modest climb) rather than cruise maintenance
2. **Remove certification-based objections** — focus on actual reliability and suitability data
3. **Expand engine trade space** — evaluate Honda variants, Viking, and other options beyond just Kawasaki
4. **Develop comprehensive failure mode analysis** — generator loss, motor loss, battery loss

## What I Need from the Board

- **Specific power numbers** for emergency operations, not cruise
- **Battery supplemental power duration** in single-generator scenario
- **Trade analysis** of more engine options, not just two
- **Failure tolerance framework** for this hybrid architecture

---

**Builder position:** I am not convinced that Kawasaki engines are required based on PROPULSION's current analysis. The power requirements appear to be based on inappropriate standards (maintaining cruise performance in emergency) and the trade space has not been fully explored.

**Next action:** PROPULSION must revise analysis with these rebuttals addressed before I will accept a 500 lb weight penalty.

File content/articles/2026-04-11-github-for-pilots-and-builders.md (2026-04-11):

---
title: "GitHub for Pilots and Builders: A Complete Beginner's Guide"
date: 2026-04-11T08:00:00-06:00
description: "Never used GitHub before? You don't need to be a software developer to use it. This guide explains what GitHub is, why AeroCommons uses it, and how to set up a project repository — using only a web browser."
tags: ["github", "community", "education", "getting-started"]
author: "AeroCommons"
article_type: "guide"
draft: false
---

AeroCommons requires that projects have a public GitHub repository. If you've never heard of GitHub — or you've heard of it but always assumed it was for software people — this guide is for you.

You do not need to write code. You do not need to install anything. Everything in this guide can be done in a web browser.

---

## What Is GitHub?

GitHub is a website where you store, organize, and track files — and where other people can find them, follow along, and contribute.

It was designed by software developers, which is why it can feel unfamiliar if your world is airplanes rather than code. But the core idea is simple and genuinely useful for aviation projects:

- Every file you upload is stored permanently
- Every change to every file is recorded — what changed, when, and a note about why
- Anyone in the world can read your files and download them for free
- People can ask questions, flag problems, and suggest changes — and all of that conversation stays attached to the specific file or topic it's about

Think of it as a combination of three things:

1. **A shared filing cabinet** — your PDFs, drawings, spreadsheets, photos, and documents all in one place that anyone can access
2. **A maintenance logbook** — a complete history of every change, who made it, and why, going back to day one
3. **An open forum** — where readers can ask questions and you can respond, with the whole conversation preserved

If you've ever lost track of which version of a drawing was the latest one, or had a file stuck on your laptop that no one else could see, GitHub solves both of those problems.

---

## Why Does AeroCommons Use It?

The short answer: because open-source aviation only works if the work is actually open.

Sending files by email creates private conversations that disappear. Google Drive links break. Facebook posts get buried. PDFs on a personal website don't have a comment thread, a change history, or a way for someone to propose a fix.

GitHub gives a project:

- A permanent, stable home for every file
- A public record of all design decisions and changes
- A community space where experienced builders can leave specific feedback on specific documents
- A way for other builders to take your work and adapt it for their own projects

This is how open-source software development works, and it turns out the same workflow maps well to aircraft design. AeroCommons itself is built on GitHub — every article, drawing, and design file for every hosted project lives there.

---

## Step 1: Create a Free GitHub Account

Go to **[github.com](https://github.com)** and click **Sign up**.

You'll need:
- An email address
- A username (this becomes part of your project's URL — something like `github.com/yourusername/your-project`)
- A password

GitHub is free for public repositories. You never need to pay for anything to use AeroCommons.

**Tip on username:** Pick something you'd be comfortable with on a business card. Your GitHub profile represents your project publicly. `jsmith-aviation` is better than `jsmith1974xp`.

---

## Step 2: Create Your Project Repository

A **repository** (usually called a "repo") is the container that holds all of your project's files. Think of it as the top-level folder for your project.

1. After signing in, click the **+** icon in the top-right corner and select **New repository**
2. Give it a name — use hyphens instead of spaces (e.g., `smith-long-ez-restoration` or `rv-14-fuel-system`)
3. Write a short description — one sentence about what the project is
4. Set it to **Public** (required for AeroCommons submission — your work needs to be readable without a login)
5. Check **Add a README file** — this creates the main description page for your project
6. Under **Choose a license**, select **CC0** or **CC BY 4.0** for design files, or leave it blank if you're not sure yet
7. Click **Create repository**

That's it. Your project now has a public home on the internet.

---

## Step 3: Set Up a Basic Folder Structure

You don't need a complex folder structure to submit a project. But a consistent layout makes your repo easier to navigate for anyone who finds it.

Here's a simple starting point for a GA project:

```
your-project-name/
├── README.md              ← project description (auto-created in Step 2)
├── docs/                  ← PDFs, design reports, analysis write-ups
│   ├── DESIGN-OVERVIEW.pdf
│   └── WEIGHT-BUDGET.xlsx
├── cad/                   ← CAD files, drawings, DXF, STEP, STL
│   └── wing-rib-template.dxf
└── photos/                ← build photos, reference images
    └── fuselage-frame-2026-03-15.jpg
```

To create a folder on GitHub using only the browser:

1. In your repository, click **Add file → Create new file**
2. In the filename box, type `docs/` — GitHub will create the folder automatically when you include a `/`
3. Add a placeholder filename like `docs/.gitkeep` (an empty file to hold the folder)
4. Scroll down and click **Commit new file**

Repeat for any other folders you want.

---

## Step 4: Upload Your Files

You don't need any special software to add files to your repository.

1. Navigate to the folder you want to upload into (e.g., click on `docs/`)
2. Click **Add file → Upload files**
3. Drag and drop files from your computer, or click **choose your files** to browse
4. Under **Commit changes**, add a short note describing what you're uploading (e.g., "Add initial weight budget spreadsheet")
5. Click **Commit changes**

That's it. The file is now online, publicly accessible, and version-tracked.

**On commit messages:** Get in the habit of writing useful notes. "Add file" tells nobody anything. "Add wing rib template — 0.032 2024-T3, based on Bingelis Chapter 4" is still just one line but tells a future reader — including future you — exactly what they need to know.

---

## Step 5: Write Your README

The README is the first thing anyone sees when they visit your repository. GitHub displays it automatically on the front page of your repo.

You don't need to write code to edit it. Click on `README.md` in your file list, then click the **pencil icon** (Edit) in the top-right corner of the file view.

A useful README for an aviation project answers these questions:

1. **What is this project?** One or two sentences.
2. **What stage is it at?** (Concept, design, under construction, flying, restoration, etc.)
3. **What's in the repository?** A short list of what files exist and what they are.
4. **How can someone follow along or get involved?**
5. **Any important disclaimers** — especially the standard aviation one: *This repository is for informational and educational purposes. Nothing here constitutes airworthiness approval. Build and fly at your own judgment and risk.*

When you're done editing, scroll down and click **Commit changes**.

---

## How to Participate Without Writing Code

A lot of the value in GitHub happens in two places that don't involve files at all.

### Discussions

The **Discussions** tab on a repository is a community forum attached directly to the project. You can:

- Ask questions about design decisions
- Share relevant experience from your own builds or flying
- Follow conversations on specific topics
- Propose ideas or flag concerns

Questions asked in Discussions are indexed and searchable. A question you ask today may help a builder three years from now find the same information.

### Issues

The **Issues** tab is for specific, trackable problems. If you find something in a document that looks wrong — a calculation that doesn't add up, a specification that conflicts with another document, a drawing that's missing a dimension — open an Issue.

Issues create a tracked record. They don't disappear into an email thread. The project maintainer can address them directly and close the issue when it's resolved, leaving a permanent record of what the problem was and how it was fixed.

You don't need to know the answer to open an issue. You just need to be specific about what you observed.

---

## Submitting Your Project to AeroCommons

Once your repository is set up and has at least a README and some documentation, you're ready to submit.

See [/submit/](/submit/) for the current requirements and submission process.

The short version: email [contact@aerocommons.org](mailto:contact@aerocommons.org) with your GitHub repository link and a brief description. We'll review it and respond within two weeks.

If you have questions about whether your project is a good fit, or if you're not sure your repository is ready, just email us — we'd rather answer a question upfront than have you spend time on a submission that needs work.

---

## GitHub's Own Resources

GitHub maintains good documentation aimed at complete beginners:

- [Getting started with GitHub](https://docs.github.com/en/get-started) — official documentation
- [GitHub Skills](https://skills.github.com/) — interactive beginner courses (free, browser-based)
- [GitHub Discussions documentation](https://docs.github.com/en/discussions) — how Discussions work

None of these require you to install anything or understand software development. The GitHub Skills courses in particular are well-designed for someone who's never touched version control before.

---

*AeroCommons is a non-profit organization. We don't charge for hosting or take ownership of submitted projects. Your work remains yours under whatever license you choose.*

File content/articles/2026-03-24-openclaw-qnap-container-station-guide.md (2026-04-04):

---
title: "Running OpenClaw on QNAP Container Station — A Practical Guide"
date: 2026-03-24T14:00:00-06:00
description: "Lessons learned deploying OpenClaw's multi-agent gateway on a QNAP NAS using Container Station, Docker Compose, and SMB-mounted volumes."
tags: ["openclaw", "qnap", "docker", "infrastructure", "container-station", "multi-agent"]
author: "AeroCommons"
summary: "A detailed walkthrough of deploying OpenClaw on QNAP Container Station — including volume mounts, gateway binding, device pairing, dashboard access, agent-to-agent communication, and every gotcha we hit along the way."
project: "community"
article_type: "methodology"
draft: false
---

If you're trying to run [OpenClaw](https://openclaw.ai) on a QNAP NAS using Container Station, this article covers the real-world problems we encountered and how we solved them. OpenClaw is a multi-agent AI gateway that orchestrates LLM-based agents with persistent sessions, tool use, and channel integrations. Running it on a NAS makes sense — always-on, network-accessible, and colocated with your data. Getting there took some work.

## Why QNAP?

Our use case is a multi-agent design board for an experimental aircraft project. Seven AI agents (a chairman/orchestrator plus six domain specialists) need to run 24/7 with persistent sessions, file-based workspaces, and Discord integration. A QNAP NAS with Container Station checks every box: Docker Compose support, always-on availability, local network access, and plenty of storage for agent workspaces and session transcripts.

## The Docker Compose File

QNAP Container Station supports Docker Compose natively. Here's the structure that works:

```yaml
services:
  openclaw:
    image: cloudlookup/openclaw:latest
    container_name: openclaw-qnap
    restart: unless-stopped
    ports:
      - "18789:18789"
      - "18791:18791"
    volumes:
      - /share/YOUR_POOL/OpenClaw:/root/.openclaw
    environment:
      - OPENCLAW_GATEWAY_BIND=lan
      - OPENCLAW_GATEWAY_TOKEN=your-gateway-token-here
      - ANTHROPIC_API_KEY=your-api-key
```

### Volume Mounts — QNAP Native Paths

This is the first place you'll get stuck. QNAP Container Station runs Docker natively on the NAS — not through WSL2 or a VM. Volume paths must use the QNAP filesystem directly.

Your shared folder path will look like:
```
/share/POOL_NAME/ShareName:/root/.openclaw
```

Find your pool name by SSH'ing into the NAS and running `ls /share/`. Common patterns are `ZFS19_DATA`, `CACHEDEV1_DATA`, or similar depending on your storage pool configuration.

**Do not** use Windows UNC paths (`\\nas-ip\share`), mapped drive letters (`Z:\`), or Docker Desktop path conventions (`/D/path`). None of these work in Container Station — they either create empty Docker volumes or fail silently.

### Port Mapping

OpenClaw uses two ports:
- **18789** — Gateway API and WebSocket (agents, sessions, channels)
- **18791** — Control UI dashboard (browser-based management)

Map both. If you're running Caddy or another reverse proxy for TLS termination, you can map different external ports.

## Gateway Configuration (openclaw.json)

The `openclaw.json` file lives inside your mounted volume at the root of the `.openclaw` directory. Here are the settings that matter for QNAP deployment.

### Bind to LAN

By default, OpenClaw binds to loopback (`127.0.0.1`), which means nothing outside the container can reach it. For a NAS deployment, you need LAN binding:

```json
{
  "gateway": {
    "bind": "lan"
  }
}
```

You can also set this via the environment variable `OPENCLAW_GATEWAY_BIND=lan` in your compose file — either works, but don't set both to different values.

### The `gateway.mode` Trap

Older OpenClaw configs (pre-2026.3.x) included a `gateway.mode` field set to `"local"`. **This field has been removed from the schema.** If your config still contains it, OpenClaw's strict validation will reject it at startup. Worse, in some beta builds, `"mode": "local"` forces the gateway to bind to `127.0.0.1` regardless of your `bind` setting — making the dashboard unreachable from any other machine.

Remove it:
```json
// REMOVE THIS — no longer valid
"gateway": {
  "mode": "local"  // ← delete this line
}
```

If you're unsure whether your config has stale keys, run `openclaw doctor --fix` inside the container:
```bash
docker exec openclaw-qnap openclaw doctor --fix
```

### Allowed Origins for the Control UI

When accessing the dashboard from a browser on a different machine, you'll get WebSocket connection failures unless the Control UI knows which origins to accept:

```json
{
  "gateway": {
    "bind": "lan",
    "controlUi": {
      "allowedOrigins": [
        "http://localhost:18789",
        "http://YOUR_NAS_IP:18789",
        "http://YOUR_NAS_IP:18791"
      ]
    }
  }
}
```

Add every IP:port combination you'll use to access the dashboard. If you're testing from multiple machines, include all of them.

### Don't Use ADVERTISE Unless You Have a TLS Proxy

OpenClaw supports `OPENCLAW_ADVERTISE_WS` and `OPENCLAW_ADVERTISE_HTTP` environment variables that tell the dashboard to connect to a specific WebSocket URL. If you set these to point at a Caddy or nginx TLS endpoint that isn't running, the dashboard will connect briefly then disconnect with a 1006 error in a loop.

**Leave ADVERTISE settings out** unless you have a working TLS reverse proxy. The dashboard will auto-discover the gateway address from the page URL.

## Device Pairing and Authentication

When you first browse to the Control UI (`http://nas-ip:18789/openclaw`), you need two things:

### 1. Gateway Token

The gateway requires a token for API access. Set it in your compose file (`OPENCLAW_GATEWAY_TOKEN`) or in the config file. Then enter it in the Control UI settings — it's not automatic.

### 2. Device Approval

Each new browser that connects creates a device pairing request. You must approve it from inside the container:

```bash
docker exec openclaw-qnap openclaw devices approve
```

Until approved, the dashboard will show a pairing screen. Check pending devices with:
```bash
docker exec openclaw-qnap openclaw devices list
```

## Multi-Agent Configuration

This is where things get interesting. If you're running multiple agents (not just a single default), there are several config sections that must work together.

### Agent List

Define your agents in `agents.list`. Each gets an `id`, `workspace`, and `agentDir`:

```json
{
  "agents": {
    "list": [
      {
        "id": "main-agent",
        "default": true,
        "workspace": "/root/.openclaw/workspaces/main",
        "agentDir": "/root/.openclaw/agents/main"
      },
      {
        "id": "specialist-a",
        "workspace": "/root/.openclaw/workspaces/specialist-a",
        "agentDir": "/root/.openclaw/agents/specialist-a",
        "model": {
          "primary": "openrouter/x-ai/grok-4.1-fast",
          "fallbacks": ["openrouter/anthropic/claude-sonnet-4-5"]
        }
      }
    ]
  }
}
```

Create the workspace and agent directories on your NAS share before starting the container, or OpenClaw will create them automatically on first run.

### Enabling Agent-to-Agent Communication

**This is the part that took the longest to figure out.** Having agents defined in the config does not mean they can talk to each other. You need three additional config sections:

#### 1. `tools.agentToAgent` — Enable the capability

```json
{
  "tools": {
    "agentToAgent": {
      "enabled": true,
      "allow": ["main-agent", "specialist-a", "specialist-b"]
    }
  }
}
```

Without this, `sessions_send` between agents is blocked.

#### 2. `tools.sessions.visibility` — Let agents see each other

```json
{
  "tools": {
    "sessions": {
      "visibility": "all"
    }
  }
}
```

The default is `"tree"` (agents only see their own subagent sessions). Set `"all"` for full cross-agent visibility, or `"agent"` to limit visibility to same-agent sessions.

#### 3. `session.agentToAgent` — Limit ping-pong depth

```json
{
  "session": {
    "agentToAgent": {
      "maxPingPongTurns": 5
    }
  }
}
```

This prevents runaway back-and-forth between agents. The maximum allowed value is 5.

#### 4. Orchestrator subagent permissions

The orchestrating agent needs permission to spawn sessions with other agents:

```json
{
  "agents": {
    "list": [
      {
        "id": "main-agent",
        "default": true,
        "subagents": { "allowAgents": ["*"] }
      }
    ]
  }
}
```

#### What `groupChat` Is NOT

We initially tried adding `"peers"` to each agent's `groupChat` config, thinking that was how you wire agents together. It's not. The `groupChat` field is exclusively for **channel group chat mention patterns** (controlling when an agent responds to @-mentions in Discord/Telegram/WhatsApp groups). It has nothing to do with inter-agent communication. OpenClaw's strict schema validation will reject unknown keys immediately.

### Subagent Timeouts and Concurrency

When your orchestrator spawns sessions with multiple agents in parallel, the default timeout and concurrency limits will bite you:

```json
{
  "agents": {
    "defaults": {
      "subagents": {
        "runTimeoutSeconds": 120,
        "maxConcurrent": 10
      }
    }
  }
}
```

- **`runTimeoutSeconds`**: Default is short. If your agents read workspace files at session startup (which they will — that's what AGENTS.md tells them to do), they can easily exceed the default timeout before producing a response. 120 seconds gives room.
- **`maxConcurrent`**: Default is 1. If you're spawning 6+ agents for a roll call, they queue up and the last ones timeout waiting. Set this to at least your agent count.

### Agent Workspace Instructions Matter

Each agent has an `AGENTS.md` file in its workspace that controls its behavior. If this file tells the agent to read 5-6 files at the start of "Every Session," it will do that on *every incoming message* — including quick `sessions_send` pings from other agents. This burns through timeouts.

Structure your agent instructions to differentiate between session startup (read everything) and direct messages (respond immediately):

```markdown
## Direct Messages
When you receive a direct message from another agent:
- Respond immediately to the question
- Do NOT re-read your entire workspace first
- Keep responses focused

## Session Startup
1. Read SOUL.md
2. Read IDENTITY.md
3. Read shared design state
...
Only run this checklist at session start or reset. Not on every message.
```

## Debugging Tips

### Config Validation

OpenClaw has strict JSON schema validation. Any unknown key causes a startup warning and best-effort config loading. Check validation with:

```bash
docker exec openclaw-qnap openclaw doctor
```

Add `--fix` to auto-repair common issues.

### Hot Reload

OpenClaw watches `openclaw.json` for changes and hot-reloads. You can edit the config file from a mapped drive or SMB share and see changes apply without restarting the container. Watch the container logs for reload confirmations.

### Dashboard WebSocket Disconnects

If the dashboard connects then immediately disconnects (error 1006), check:
1. `allowedOrigins` includes your browser's origin
2. ADVERTISE settings aren't pointing to a dead proxy
3. Gateway is bound to `lan`, not `loopback`

### Agent Not Responding

If specific agents don't respond to `sessions_send`:
1. Check `maxConcurrent` — agents queued beyond the limit will timeout
2. Check `runTimeoutSeconds` — agents reading large workspaces need more time
3. Check the agent's model and fallback — if both the primary model and fallback are unavailable via your API provider, the agent silently fails
4. Check session transcripts — large transcripts slow context loading

## What We'd Do Differently

1. **Start with `openclaw doctor --fix`** after any config change. It catches schema issues immediately.
2. **Set `maxConcurrent` to your agent count from day one.** The default of 1 makes multi-agent setups appear broken.
3. **Don't confuse `groupChat` with agent routing.** The docs are clear once you find the right page, but the field name is misleading if you're coming from a multi-agent mindset.
4. **Use environment variables for secrets**, not inline JSON values. OpenClaw supports `${ENV_VAR}` substitution in config strings.
5. **Test agent communication with a simple roll call** before attempting complex multi-round protocols.

## Current Stack

- **QNAP NAS** with Container Station (Docker Compose)
- **OpenClaw** v2026.3.1-beta.1 (`cloudlookup/openclaw:latest`)
- **7 agents** — orchestrator on Claude Sonnet 4, domain agents on Grok 4.1-fast via OpenRouter
- **Discord** channel integration for human interaction
- **Persistent sessions** with file-based workspaces on NAS shared storage

The system runs 24/7, agents maintain context across conversations, and the orchestrator can convene multi-agent board meetings on demand. Getting here required solving a chain of infrastructure problems — volume paths, network binding, device pairing, origin allowlists, agent-to-agent wiring, timeout tuning — but the result is a self-hosted multi-agent system that doesn't depend on any cloud orchestration layer.

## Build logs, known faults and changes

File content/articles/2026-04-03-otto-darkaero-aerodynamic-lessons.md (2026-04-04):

---
title: "Otto Aerospace & Dark Aero Aerodynamic Lessons for MAOS"
date: 2026-04-03T09:00:00-06:00
description: "Extracting key aerodynamic methodologies, trade spirals, and design insights from Otto Aerospace and Dark Aero for application to MAOS pod‑and‑boom high‑wing configuration."
tags: ["aerodynamics", "analysis", "design-decisions", "structures", "systems"]
author: "AERO (Aerodynamics & Flight Mechanics Lead)"
project: "maos"
article_type: "analysis"
draft: false
---

# Otto Aerospace & Dark Aero Aerodynamic Lessons for MAOS

**Date:** 2026-04-03  
**Author:** AERO (Aerodynamics & Flight Mechanics Lead)  
**Purpose:** Extract key aerodynamic methodologies, trade spirals, and design insights from Otto Aerospace and Dark Aero for application to MAOS pod‑and‑boom high‑wing configuration.

---

## 1. Otto Aerospace – Laminar Flow Revolution

### Key Aerodynamic Decisions

- **Full‑airframe laminar flow** – Otto maintains smooth, attached airflow over **87% of the airfoil and fuselage** at transonic speeds, reducing viscous drag (≈55% of total drag) by **35%** compared to conventional turbulent‑flow designs [[1]](https://ottoaerospace.com/technology/laminar-flow/)[[2]](https://green.simpliflying.com/p/otto-aviation-claims-laminar-flow).
- **Slotted Natural Laminar Flow (SNLF) wings** – Wing slots manage pressure gradients to delay transition, validated in European Transonic Wind Tunnel within **1% of predictions** [[7]](https://aviationweek.com/aerospace/emerging-technologies/otto-aerospace-begins-slotted-natural-laminar-flow-wing-tests).
- **Ultra‑smooth manufacturing** – Eliminates rivets, screws, panel joints, and surface imperfections that trigger premature turbulence. Uses advanced composites, tight tolerances, and windowless fuselage for uninterrupted surface [[1]][[2]].
- **High‑aspect‑ratio wings (Celera 500L)** – Long, narrow glider‑like wings (glide ratio >22:1) positioned aft of mid‑fuselage to enhance laminar run. Later Phantom 3500 adopted wider conventional wings for cabin volume, trading some aspect ratio for practicality [[3]](https://aerospace.aerosociety.com/aerospace/aerospace-april-2021/features/going-with-the-flow).

### The “Virtuous Cycle” Trade Spiral

Otto’s laminar flow triggers a self‑reinforcing **drag‑weight‑power spiral**:

1. **Lower drag** → **62% lower fuel burn** → smaller fuel load → lighter aircraft.
2. **Lighter aircraft** → smaller engine required → further weight reduction.
3. **Smaller engine** → lower power demand → even less fuel needed.

This “virtuous cycle” enables **non‑linear improvements**: drag down → engine/structural weight down → fuel spiral downward, culminating in **40% less Jet‑A fuel** than comparable business jets [[1]][[2]][[4]](https://ottoaerospace.com/technology/virtuous-cycle/).

### Validation Approach

- **AI‑driven aerodynamic optimization** – Proprietary AI model (Luminary) trained on CFD and wind‑tunnel data reduces design iteration from months to one day [[3]](https://ottoaerospace.com/news/otto-aerospace-develops-proprietary-ai-model-for-aerodynamic-innovation/).
- **European Transonic Wind Tunnel (ETW) tests** – Slotted wing performance matched predictions within 1%.
- **Flight‑test demonstrator** – Celera 500L provided real‑world validation before scaling to Phantom 3500.

---

## 2. Dark Aero – High‑Speed Kit‑Plane Efficiency

### Key Aerodynamic Decisions

- **Thin, low‑drag airfoils** – Airfoil selection prioritizes thin profiles (~12% thickness‑to‑chord) with low camber to minimize profile drag, varying spanwise from thicker roots to thinner tips for structural and aerodynamic efficiency [[5]](https://www.simscale.com/blog/darkaero-wing-stall-characteristics/).
- **Moderate aspect ratio** – Wing span 23.5 ft, area ≈66.7 ft² (wing loading 22.5 lb/ft² at 1500 lb gross), yielding aspect ratio ≈8.3. Avoids winglets, relying on clean planform taper to reduce induced drag [[6]](https://www.kitplanes.com/dark-aero-1/).
- **Progressive stall design** – Wing stalls root‑first, progressing outward, preserving aileron control at tips. Validated via CFD (SimScale) at angles of attack from 0° to beyond stall [[5]].
- **Extremely clean external geometry** – Split flaps (no exposed rails), internal control actuators (no external horns), split rudder doubling as speed brake, retractable gear housed entirely in fuselage, no wing penetrations [[6]].

### Drag‑Reduction Techniques

- **Carbon‑fiber wet wing** – One‑piece construction eliminates sealant joints and external fuel vents.
- **Internal linkages** – All pushrods and bellcranks inside the wing/fuselage, eliminating parasite drag from control horns.
- **Split rudder speed brake** – Eliminates separate speed‑brake surfaces and their drag/weight penalties.
- **Low‑camber, thin airfoils** – Sacrifices some CLmax for lower cruise drag; stall speed 70 mph acceptable for a 275 mph cruise design.

### Performance Targets & Validation

- **Targets:** Cruise 275 mph (240 kts), stall 70 mph, range 1700 statute miles, climb 2500 ft/min, wing loading 22.5 lb/ft² [[6]].
- **Validation:** Thousands of CFD simulations (SimScale), wind‑tunnel testing of 3D‑printed models at University of Wisconsin–Madison, and planned flight testing of prototype [[5]][[6]].

---

## 3. Trade Spirals & Optimization Approaches

| Company | Core Trade Spiral | Optimization Approach |
|---|---|---|
| **Otto Aerospace** | Laminar flow → drag reduction → smaller engine → lighter structure → less fuel → further drag reduction. | AI‑driven design loop; precision manufacturing for surface quality; wind‑tunnel‑validated SNLF wings. |
| **Dark Aero** | Thin airfoils & clean geometry → low profile drag → higher cruise speed → smaller fuel fraction → lighter weight → further drag reduction. | CFD‑guided stall progression; internal controls; carbon‑fiber monolithic construction. |

Both companies embrace **iterative, simulation‑heavy design** that couples aerodynamics with weight and propulsion from the outset, rather than treating them as sequential disciplines.

---

## 4. Applicability to MAOS (Pod‑and‑Boom, High‑Wing)

### Strengths We Can Borrow

1. **Laminar‑flow airfoil** – MAOS already uses Riblett GA35‑615, a laminar‑flow section. Otto’s emphasis on **surface smoothness** is directly applicable: we must avoid steps, gaps, and protruding fasteners on wing and fuselage.
2. **Internal control runs** – Dark Aero’s internal linkages are feasible for our aileron and elevator controls; eliminates external horn drag.
3. **Split rudder speed brake** – Our twin‑boom configuration could incorporate a split rudder that opens as a speed brake, saving separate drag devices.
4. **Progressive stall** – We can tailor washout or airfoil spanwise variation to ensure root‑first stall, preserving roll control at the tips.
5. **CFD‑backed stall validation** – Use XFLR5/AVL to simulate stall progression across the wing, similar to Dark Aero’s SimScale workflow.

### Constraints & Differences

- **High wing vs low wing** – High wing favors ground clearance and visibility but complicates laminar flow on the upper surface due to fuselage junction. Otto’s mid‑wing placement may be more optimal; we must manage junction fairings carefully.
- **Pod‑and‑boom** – Our twin‑boom tail adds interference drag; Otto’s clean fuselage‑tail transition is simpler. Need to optimize boom‑wing and boom‑tail junctions.
- **Series hybrid** – Weight of batteries and electric motor may limit the “virtuous cycle” of weight reduction. However, laminar drag reduction can lower power demand, possibly allowing smaller motor/battery and weight savings.
- **Homebuilder‑level manufacturing** – Otto’s ultra‑smooth composites require industrial precision; we must achieve adequate surface quality with garage‑friendly methods (e.g., molded composite skins, careful filling/sanding).

---

## 5. Specific Recommendations for MAOS

### Immediate Actions (Next 30 Days)

1. **Surface‑smoothness specification** – Draft a **Surface Quality Standard** for MAOS wings and fuselage, limiting step/gap heights to ≤0.005 in (0.13 mm) and requiring filler/sanding of all joints.
2. **CFD stall progression study** – Run XFLR5 viscous analysis across a range of angles of attack (0°–20°) to verify root‑first stall behavior of the GA35‑615 wing with planned washout.
3. **Internal control layout** – Sketch internal pushrod routes for ailerons and elevator; identify bellcrank locations that stay inside wing and boom profiles.

### Medium‑Term (Next 6 Months)

4. **Split‑rudder speed‑brake feasibility** – Model the twin‑boom rudders as split surfaces; assess actuation loads and drag reduction potential.
5. **Junction fairing design** – Use OpenVSP to design wing‑pod and boom‑tail fairings that minimize interference drag (Otto’s philosophy of “no unnecessary protrusions”).
6. **Trade‑spiral analysis** – Quantify the impact of a 10% drag reduction (via laminar flow and clean geometry) on required motor power, battery size, and gross weight. Determine if a “virtuous cycle” can be triggered within our hybrid‑electric constraints.

### Long‑Term (Before First Flight)

7. **Manufacturing quality plan** – Develop a **garage‑precision** process for achieving smooth composite skins: use CNC‑cut foam cores, vacuum‑bagged epoxy/glass, and filler/primer/sanding protocols.
8. **Stall‑warning system** – Given our root‑first stall design, install an angle‑of‑attack sensor that alerts pilot at 80% of critical α (Dark Aero’s progressive stall provides natural warning; we can augment with an electronic cue).

---

## 6. Conclusion

Otto Aerospace demonstrates that **full‑airframe laminar flow** is not just a drag‑reduction tactic but a **system‑level enabler** that cascades into weight, power, and fuel savings—a true “virtuous cycle.” Dark Aero shows that **clean, internally‑linked geometry** combined with **CFD‑validated stall behavior** can yield remarkable cruise efficiency in a home‑built kit.

For MAOS, the highest‑value takeaways are:

1. **Treat surface smoothness as a non‑negotiable requirement** – it is the entry ticket to laminar flow.
2. **Design the wing to stall root‑first** – use computational tools to confirm progressive stall.
3. **Hide all control linkages** – every external horn is a drag penalty we can avoid.
4. **Explore a split‑rudder speed brake** – one surface, two functions, zero added penetrations.

These lessons align with MAOS’s core philosophy: a **comfortable, go‑places traveling machine** that is efficient, predictable, and buildable in a home shop.

---

## References

1. Otto Aerospace – Laminar Flow Technology (https://ottoaerospace.com/technology/laminar-flow/)
2. Green.SimpliFlying – Otto Aviation Claims Laminar Flow (https://green.simpliflying.com/p/otto-aviation-claims-laminar-flow)
3. Otto Aerospace – AI Model for Aerodynamic Innovation (https://ottoaerospace.com/news/otto-aerospace-develops-proprietary-ai-model-for-aerodynamic-innovation/)
4. Otto Aerospace – Virtuous Cycle (https://ottoaerospace.com/technology/virtuous-cycle/)
5. SimScale – DarkAero Wing Stall Characteristics (https://www.simscale.com/blog/darkaero-wing-stall-characteristics/)
6. Kitplanes – Dark Aero 1 (https://www.kitplanes.com/dark-aero-1/)
7. Aviation Week – Otto Aerospace Begins Slotted Natural Laminar Flow Wing Tests (https://aviationweek.com/aerospace/emerging-technologies/otto-aerospace-begins-slotted-natural-laminar-flow-wing-tests)

*All web references accessed 2026‑04‑03.*

---

*This research was conducted by the AERO agent as part of the MAOS design board's continuous learning and technology assessment process.*

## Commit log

2026-03-19 Claude thread export
2026-03-19 Add board session BOARD-001 technical review
2026-03-24 Add Decision D-001 (400V bus voltage) and educational article on aircraft voltage design
2026-03-25 Add two new technical articles: single vs twin engine architecture analysis and Donut Labs motor evaluation
2026-03-26 Add two new technical articles: motor demagnetization cooling analysis and cantilever vs braced wing decision
2026-03-26 Add board review: Fly-by-wire advantages for pod-and-boom aircraft
2026-03-27 Add removable wing attachment guide article - structural design for trailer-transportable homebuilts
2026-03-27 Rewrite removable wing article: non-penetrating design, 8-12g safety factors, pressure vessel focus
2026-03-27 Add galvanic corrosion guide and Lancair/Veloce case studies articles
2026-04-02 Add refactored wing loading analysis with corrected Bonanza A-35 data and wing rigidity effects
    - Corrects Bonanza A-35 wing loading: 14.6 lb/ft² (not 19.0 lb/ft²)
    - Incorporates wing rigidity analysis (Boeing vs Airbus vs Diamond)
    - Adds altitude capability factor for Appalachian crossings
    - Updates MAOS target to 18-22 lb/ft² with composite flexible wing
    - Removes Lancair caution section per builder request
    - Refactors safety analysis with no-flap design acceptance
2026-04-02 Rewrite wing loading article with correct physics: high W/S = smooth ride
2026-04-03 Add MVS Phase 1: Component list and cost summary for camera-only cockpit
2026-04-03 Add STRUCTURES and SYSTEMS research articles: composite construction & waste heat systems
2026-04-04 Regulatory article
2026-04-05 Add analysis: MAOS-ECS Phase 1 environmental control system BOM
    Phase 1 BOM and bench test plan for MAOS Environmental Control System
    covering AC, heating, and pressurization using 400V EV-market components.
2026-04-05 Add analysis: MAOS propulsion redundancy architecture and battery selection
    Evaluates six series-hybrid redundancy architectures, sizes the 30-minute
    emergency battery reserve, and compares five battery chemistries. Establishes
    2G+1B+2M coaxial as the baseline architecture recommendation.
2026-04-05 Update analysis: add Donut Lab solid-state battery to comparison matrix
    Adds Donut Lab to chemistry table, weight table, and cell candidates table
    with specs from their published site and a note on the controversy around
    the simultaneous energy/power/cycle-life claims.
2026-04-05 Add analysis: MAOS generator selection and voltage architecture review
    Evaluates axial-flux PM generator candidates (Emrax 268, Beyond Aviation AXM3,
    Magnax) with BOM, ICE shaft interface options, and reopens the 400V vs 800V
    bus voltage decision based on Samson Sky Skybrid's 800V architecture choice.
2026-04-05 Add analysis: MAOS propulsion redundancy architecture and battery selection
    Honest cost comparison across three drivetrain configurations showing the
    budget series hybrid path (~$81k) is defensible against a twin-engine
    conventional. Rehabilitates large-displacement motorcycle engines for
    generator duty. Documents the LFP battery weight problem and the
    tradeoffs that budget path requires.
2026-04-05 Update analysis: add Skybrid electric transmission vs true series hybrid comparison
    Documents that Samson Sky Skybrid operates without a battery buffer,
    making it an electric transmission rather than a true series hybrid.
    Analyzes the redundancy and control implications and explains why MAOS
    must retain the battery for both control tractability and IFR safety.
2026-04-05 Add analysis: MAOS 1G+1B+2M propulsion architecture decision
    Records the propulsion architecture selection: single ICE generator,
    single battery pack, dual independent electric motors. Includes power
    budget, three-layer failure analysis, battery bypass explanation,
    component direction, and dual cost summaries for Rotax vs motorcycle
    engine paths.
2026-04-05 Fix: single motor failure classified as emergency per pilot convention
2026-04-05 Fix: battery+motor compound failure also classified as emergency
2026-04-06 Add pod occupant study: visualization scripts and output PNGs
    Matplotlib-based occupant study for MAOS pressure pod interior.
    Includes baseline (58"H/4" floor, -1.0" headroom FAILS) and 5 variants
    A-E evaluating 58-62"H pod heights with 2" and 4" floor structures.
    Variant E (60"H, 2" floor, +3.0" headroom) identified as recommended.
    Reference human mesh (SimpleHuman.glb) included.
2026-04-06 Add MAOS pod OpenVSP 3D geometry (v1.1)
    First true 3D model of the MAOS pressure pod generated by OpenVSP 3.48.2
    via headless vspscript. 5-section fuselage with elliptical XSecs:
    52"W x 58"H at mid-body, 156" total length, XS_POINT nose/tail caps.
    Exports: .vsp3 (native), .obj, .stl. Matplotlib 3D preview included.
    [maos_pod.obj, maos_pod.stl]
2026-04-06 Add MAOS aircraft VSPAERO first-pass analysis
    OpenVSP 3.48.2 VLM (wing + H-tail + V-tail only) + Swet body drag estimate.
    Alpha sweep -2° to +12°, Mach 0.234 (155 KTAS SL, AR=7.41, Sref=121.5 ft²).
    Key results:
    - CL_cruise = 0.263 at α ≈ 2.8°
    - L/D cruise = 16.3 — exceeds L/D=14 propulsion sizing target by +2.3
    - Peak L/D ≈ 16.6 at α ≈ 6°
    - CD0_bodies (Swet) = 0.01242 (pod + boom + fixed gear)
    Files:
    - maos_aircraft_v1.vspscript — parametric geometry + VSPAERO sweep script
    - maos_aircraft_v1.vsp3 / .stl — generated model
    - maos_aircraft_polar.png — four-panel drag polar chart
    - render_polar.py — polar file parser and chart renderer
    Note: CG placed at nose (X=0); pit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
    [maos_aircraft_v1.stl]
2026-04-06 First renderings
    [maos_aircraft_v1.stl]
2026-04-06 Design iterations
    [maos_aircraft_v1.stl]
2026-04-08 Pod geometry updates, human sizing analysis, and area progression article
    - Pod widened to 60" outer (POD_W 4.333→5.0 ft) for walk-through aisle + shoulder room
    - XSec_1 and XSec_2 updated to squircle EditCurve shape at 60" width in vsp3
    - vspscript synced: POD_W, XSec_3 width, and detailed GUI note for squircle sections
    - Human sizing visualization: 95th-pct male tandem/side-by-side analysis (pod_human_sizing.py)
    - Updated STL export and render preview from revised vsp3
    - New article: smooth area progression, Jones equivalent body, interference drag math
    [maos_aircraft_v1.stl]
2026-04-08 Add area progression article, pylon+ICE geometry variant, and pod cross-section updates
    - New article: smooth area progression, Jones equivalent body theorem,
    Sears-Haack reference, interference drag estimates, MAOS application
    - maos_aircraft_v1.vsp3: wider XSec_1 (60"), narrower XSec_2 (52.8"),
    squircle-style cabin cross-section shape from GUI session
    - maos_aircraft_v1_ICE_BUMP_Pylon.vsp3: pylon-mounted wing (Z=3.0),
    ICE nacelle geometry on top of wing (needs sizing correction in GUI)
    - maos_pylon_ice_render.png: four-view render of pylon+ICE configuration
2026-04-09 Add series hybrid GA case article: piston vs turbine comparison
    Explains why most GA pilots overlook series hybrid architecture, makes
    the redundancy and performance arguments, and compares Rotax 915 and
    M250-C18 paths for MAOS with mission fuel weight analysis.
2026-04-09 Add pylon+ICE geometry variants, motor renders, and design decisions update
    - maos_aircraft_v1_ICE_BUMP_Pylon.vsp3: updated pylon wing + ICE nacelle variant
    - maos_aircraft_v1_ICE_BUMP_Pylon_Motors.vsp3: new variant with boom motor geometry
    - maos_pylon_ice_*.png: eight-view render set of ICE_BUMP_Pylon configuration
    - maos_pylon_ice_motors_render.png: four-view render of Motors variant
    - design-decisions.md: battery placement section (P1/P2 recommendations, 35 kWh target)
2026-04-09 Fix Pipistrel Panthera engine attribution in series hybrid article
    Panthera uses Lycoming IO-540 (~235 hp) not Rotax 914, and achieves
    ~199 KTAS not 165 KTAS. Reframed comparison: MAOS approaches Panthera
    speed on 141 hp Rotax vs 235 hp Lycoming — a 40% power reduction for
    the same cruise class.
2026-04-10 Add owner-produced parts pillar to AeroCommons website
    - Add Regulatory Pillars section (14 CFR 21.191 EAB vs 21.9(a)(5) owner-produced parts) to homepage
    - Add Beech B200-202 pitch control bearing as third project in data/projects.yaml
    - Update hero subtitle and footer to reflect both regulatory frameworks
    - Add CSS for pillars section with responsive layout
2026-04-11 NACA Duct Research
2026-04-12 3D Models
    [maos_aircraft_ICE_bump_pylon.obj, maos_aircraft_v1_ICE_BUMP_Pylon.stl, maos_aircraft_v1_ICE_BUMP_Pylon_hires.stl]
